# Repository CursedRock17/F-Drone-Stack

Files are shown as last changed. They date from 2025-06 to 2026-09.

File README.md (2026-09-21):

# Welcome to the F-Drone-Stack

## Introduction
This is project for the [MATRIX Lab](https://matrix.umd.edu/) at the University of Maryland's SMART
building. It utilizes dRehmFlight (by nickrehm) as a flight controller.

The intent of the project is to create a stack for replicable, autonmous
drones. These drones utilize a soft-core ARM Cortex M3 on an FPGA to
allow the software to not be restricted to any certain chip which can
be used on quadrotors of any size or scale.

Clone this repository with the version you'd like: `git clone https://github.com/CursedRock17/F-Drone-Stack.git -b humble`

## Software Setup
--------------------------------------------
### Required External Resources (Libraries)
 - Vivavdo [Download](https://www.amd.com/en/products/software/adaptive-socs-and-fpgas/vivado/vivado-buy.html)
 - ARM [Cortex M3](https://developer.arm.com/documentation/101483/0000/introduction/directory-structure) replicable architecture for Artix A7 FPGA

### CRSF Protocol Overview
 - CRSF Telemetry [PX4 Guide](https://docs.px4.io/main/en/telemetry/crsf_telemetry.html)
 - Telemtry [Messages](https://docs.px4.io/main/en/telemetry/crsf_telemetry.html#telemetry-messages)

<details>
<summary> Arduino Setup Steps </summary>

Prerequiste Installs

1. Install [Arduino](https://www.arduino.cc/en/software/) for your respective system
2. Install the [Teensyduino](https://www.pjrc.com/teensy/td_download.html) add-on for your respective system
   : *Note* Make sure you're using versino 1.57.3.
3. Install the [CRSFforArduino](https://github.com/ZZ-Cat/CRSFforArduino) library
4. Navigate to the directory in which you cloned the repo: `cd ~/user/F-Drone-Stack`
5. You have successfully installed the software stack!

</details>

<details>
<summary> Vivado Setup Steps </summary>

** Be Warned Vivado is a **FAT** install **
1. Install [Vivado](https://www.xilinx.com/support/download/index.html/content/xilinx/en/downloadNav/vivado-design-tools.html) for your OS
    1. For Linux: Download the `.bin` file, open up a terminal, `cd ~/Downloads`
    2. Make the file installable: `chmod +x <installer_name>.bin`
    3. Run install: `sudo <installer_name>.bin`
2. Go through the setup manager, you only need the free version for this project
    1. In Detail: Sign-in with your AMD account
    2. Install Vivado ML Standard
    3. In Devices, add "7-Series > Artix-7 FPGAs"
    4. Agree to all the licenses, scrolling to the bottom
    5. Install in the "/tools/Xilinx" directory, or wherever's best for you
    6. Cry as you watch your RAM wither away
        1. If you're on Linux, install the cable drivers, so we can program it: `cd /tools/Xilinx/data/xicom/cable_drivers/lin64/install_script/install_drivers`
        2. Make sure you're added, sudo adduser $USER dialout
    7. Source the install: "source /tools/Xilinx/<version>/settings64.sh"
    8. Run the program, (Linux): `vivado` (Windows): double click app
3. Install the [ARM Cortex IP](https://developer.arm.com/documentation/101483/0000/?lang=en)
    1. See if you're respective university/company already has it (UMD does!), if not apply for the [DesignStart program](https://www.arm.com/resources/program-reg/flexible-access-designstart-tier)
    2. Once you gain access go to [ARM Developer's Product Hub](https://developer.arm.com/downloads/)
    3. Go to [DesignStart Physical IP](https://developer.arm.com/downloads/search?programme=DesignStart&term=Cortex-M3+Processor&entitled=false) and grab the `Cortex M3`
4. Boot up Vivado, we can do so by sourcing the shell script:

</details>

### Running the Software
1. Open the Arduino IDE
2. We now need to open the correct version of the software to make adjustments: In the top left corner of the IDE go to “File > Open > ~/user/F-Drone-Stack/dRehmFlight/Versions/dRehmFlight_Teensy_BETA_1.3”
3. We now need to select the correct board, which in our case is the Teensy 4.1 (but 4.0 works just fine). Go to “Tools > Board > Teensy > Teensy 4.1”. Make sure CPU speed is “600 mHz” and USB type is “Serial”
4. At this point in time acquire a data transfer USB and plug it into the Teensy. We can hit “Sketch > Upload” and the board should flash the Arduino file
    1. Note an error I came across was not having the rules for the Teensy board already installed. So if you come across this error do the following:
    2. Open up a terminal window and go to the rules directory, on Linux: “cd /etc/udev/rules.d” or make the directory if it doesn’t exist “mkdir -p /etc/udev/rules.d”
    3. We need to add the Teensy Rules File, now “touch 00-teensy.rules”
    4. In the text editor of your choice, copy the entire file linked above and paste it into the file. Reflash dRehmFlight and the upload should complete
5. Enjoy!

### Flight Computer Setup Steps (Intelligence Stack)

Provides to sort of intelligence like waypoint provision, pose estimation,
and path planning access.

[In Flight Computer Section](./FlightComputer).

### Hardware Setup

[In Hardware Section](./Hardware), steps to find needed parts, assemble,
and troubleshoot the mechanical and electrical parts to a sample drone

You can also find any CAD Files and eCAD files pertaining to the drone

### Handset Setup 

While this code will work autonomously, it's a good idea as always to 
allow manual control via a human pilot, for the testing I used to the 
[Radiomaster Zorro](https://radiomasterrc.com/collections/zorro-radio-control-series/products/zorro-radio-controller).
We will flashing everything through UART and over Wifi.

1) Download the [ExpressLRS Configurator](https://github.com/ExpressLRS/ExpressLRS-Configurator/releases/)
it will make it easier to bind the Handset (Tx) to the ELRS Receiver (Rx)
2) You can plug your Teensy into a computer to get 5V passing through the receiver 
Once it is on, open that Configurator application. There will some options:
  - Releases : Whatever version you installed 
  - Device Category : BETAFPV 2.4 GHz 
  - Device : BETAFPV 2400 RX Lite 
  - Flashing Method : UART
Now, hit `Build and Flash`, it might take a couple minutes.
3) We can now flash the receiver over wifi, download the [ELRS Firmware](https://support.betafpv.com/hc/en-us/articles/24408930358169-Firmware-for-ELRS-Lite-Receiver-2-4GHz)
before you actually flash, since you'll lose access to the internet. 
After waiting about 30 secs there should be a new wifi network:
`ExpressLRS RX` with the password "expresslrs". Join it! 
4) It will automatically put you in the browser so that you can acccss 
the `Firmware Update` section, *Select* the firmware you just downloaded.
Now I had some trouble here where it would tell me there's a mismatch and kick me
out, this happened a couple of times, just repeat it 3-4 times and it will download for you.
5) We can now pair the handset, in the Zorro `Hardware` section (Page 6 in SYS) 
there's a subgroup : `Bind Configuration`, use the right scroll wheel, then press in
6) We will now do the same wifi style setup but with the TX instead.
7) Congrats the two items should be paired!

After you've paired the two together we should tune our controller for the drone.

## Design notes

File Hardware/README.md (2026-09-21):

# Hardware Section and Setup

Welcome to the mechanical and electrical parts section of the project,
here you can find the entire process of building a custom drone.

### Parts List

#### Electrical Components

| Item | Part | Datasheet | Link |
|---|---:| ---:| ---:|
| MCU/FC | Teensy 4.0 | [Datasheet](https://www.pjrc.com/store/teensy40.html) | [Link](https://www.electromaker.io/shop/product/teensy-40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)
| IMU | HiLetgo GY-521 | [Datasheet](https://mm.digikey.com/Volume0/opasdata/d220001/medias/docus/2204/SEN0142_Web.pdf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) | [Link](https://www.amazon.com/HiLetgo-MPU-6050-Accelerometer-Gyroscope-Converter/dp/B078SS8NQV)
| Radio Rx | ELRS Lite RX 2.4 GHz | [Datasheet](https://support.betafpv.com/hc/en-us/articles/4402596816409-Manual-for-Nano-Receiver) | [Link](https://betafpv.com/products/elrs-lite-receiver?variant=39582961664134)
| ESC (4in1) | Mamba F30 Mini | [Datasheet](https://cdn.shopifycdn.net/s/files/1/0027/2708/4144/files/MK4_F405_MINI_ICM42688P.jpg?v=1658891020) | [Link](https://speedyfpv.com/products/diatone-mamba-f30mini-2-5s-30a-brushless-4-in-1-esc-blheli_s-dshot600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)
| BEC (5V) | MP1584EN Mini | [Datasheet](https://www.makerfabs.com/desfile/files/MP1584.pdf) | [Link](https://www.amazon.com/MP1584EN-DC-DC-Converter-Adjustable-Module/dp/B01MQGMOKI)
| Battery (2S) | GNB Li-ion 2S | None | [Link](https://www.gaoneng.shop/products/gaoneng-gnb-2s-7.4v-3000mah-10c-xt60-li-ion-battery-made-with-sony-18650-vtc6)
| Motors (x4) | HGLRC 11000KV Brushless | [Datasheet](https://www.hglrc.com/products/specter-1202-5-11000kv-brushless-motor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) | [Link](https://www.hglrc.com/products/specter-1202-5-11000kv-brushless-motor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)
| Optical Flow | Matek 3901-L0X | [Datasheet](https://www.mateksys.com/?portfolio=3901-l0x#tab-id-2) | [Link](https://www.getfpv.com/mateksys-optical-flow-lidar-sensor-3901-l0x.html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)
| Wires | 28awg Wires + Connectors| [Datasheet](https://www.molex.com/en-us/products/part-detail/151340402?display=pdf) | [Link](https://www.amazon.com/Keszoox-Pre-Crimped-Compatible-Controller-Connectors/dp/B09F3TQS9V?th=1)
| Capacitor | 25V 330uF | None | [Link](https://www.digikey.com/en/products/detail/rubycon/25YXF330MEFCT810X12.5/9553865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)

#### Mechanical Parts

| Item | Part | Datasheet | Link |
|---|---:| ---:| ---:|
| Drone Frame | Carbon Fiber Micro UAS  | None | None
| Screws(x7) | M2 12mm Metal Screw | None | None
| Nuts(x7) | M2 Metal Nut | None | None
| Screws(x2) | M3 12mm Nylon Screw | None | None
| Nuts(x2) | M3 Nylon Nut | None | None
| Custom PCB | Copper Board | The PCB in the Hardware Section | [Hardware](TeensyDrone) 
| Battery Mount | Battery Holder | None | None
| Op Flow Mount | Op Flow Holder | None | None
| Legs(x4) | TPU printed Legs | Legs in the TeensyCAD section | [TeensyCAD](TeensyCAD)
| JST SH | 8-Pin Vertical Shrouded | [Datasheet](https://www.jst-mfg.com/product/pdf/eng/eSH.pdf) | [Link](https://www.digikey.com/en/products/detail/jst-sales-america-inc/BM08B-SRSS-TB/926700)
| MX PicoBlade (x2)| 4-Pin Vertical Picoblade| [Datasheet](https://www.molex.com/en-us/products/part-detail/533980471?display=pdf) | [Link](https://www.digikey.com/en/products/detail/molex/0533980471/699068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)
| MX PicoBlade (x4)| 3-Pin Male Connector | [Datasheet](https://www.molex.com/en-us/products/part-detail/2181100301) | [Link](www.digikey.com/en/products/detail/molex/2181100301/14309272?utm_source=oemsecrets&utm_medium=aggregator&utm_campaign=buynow)
| Gemfan 3025  (x4)| 2 Blade Propeller | [Datasheet](https://grabcad.com/library/gemfan-t-3025-1) | [Link](https://newbeedrone.com/products/gemfan-3025-pc-2-blade-propeller)

### Drone Characteristics
- Drone Weight: 97g
- 2S Li-Ion Battery Weight: 104g 
- Battery Holder Weight: 5g 
- *Total Weight*: 206g
- CG:
- Motor Thrust vs PWM Signal Curve:

### Assembly

1) Grab your drone Frame, electrical components, and turn on your soldering iron
2) Before you do anything, ensure your PCB's PWR/GND doesn't have any shorts
by testing with a multimeter, there should be 1 big GND plane
3) Use helping hands to hold the PCB still, start by soldering pinouts to tracks
    1) Start with the BEC, ensure it's in the correct orientation, arrow points left
    and solder pins 3 & 7, using the PCB editor as a guide. I placed 2 pin
    headers in each section, soldered those into the board, then sniped them flush
    2) Next we solder the Teensy 4.0 going in the clockwise direction, starting
    with Vin (the top right pin), the USB port should face the BEC, skip 4pins,
    then solder pins 21, 20, (skip 2), 17, 16, (skip 6), 3.3V, (skip 4), 9,
    8, 7, 6, (skip 4), 1, 0. You may want to solder header pins in the vertical
    pinouts of the Teensy itself, then solder matching sockets (14 pin) into
    the board itself, for easy removal of the Teensy.
    3) Solder all 4 JST headers, the 8-pin on the left, two 4-pins on the right
    and another 4-pin on the lower on the right
4) Mount the PCB to the drone frame itself, using three M2 (2") screws, they
   should lie underneath the ESC, so taking it off must be done in reverse
5) The next step is soldering 28-awg wire(Or whatever you have) with
   connectors to the components
   There are 4 components which are wired in this way:
     - ESC Motors (3 connectors each, 4 connectors) Goes RBY for colors,
     string and solder those wires to the edge power pads, then we can
     run the other end of the connector into the corresponding motor
     connectors, so they should click into each other (MX Picoblade)
     male -> female and female -> male
     - ESC (8 pin connector, using 6, top left)
     - IMU (4 pin connector, top right)
     - Optical Flow (4 pin connector, middle right)
     - ELRS (4 pin connector, bottom right)
6) *Optional* : Put a layer of Kapton tape on the bottom of the PCB
7) After we've solder all the components onto the board, we can mount things
   Things have to mounted in a weird order so that we save space
    1) Run the 3 mounting screws for the PCB, through the PCB, but not onto the
    frame
    2) Mount the ESC to the PCB using 4 M2 (2") screws with the custom spacers
    on the opposite side of the ESC, finishing with a M2 nut on the other side
    of the board
    3) The other component being mounted to the PCB is the IMU, with two
    3" screws 12mm Nylon screws. Run the screws through the IMU into rubber
    spacers (gummies) which are finished up by some tight fitting nuts on the
    other side of the PCB
    4) Flip the PCB + Drone over, slotting the mounting screws through and as
    always, finish on the otherside with M2 nuts for each of the 3 screws
8) We must now screw in the battery pack, to the bottom with the holder
9) **Before** plugging in your external connectors or the Teensy, you need to
test the BEC, since it's controlled with a potentiometer. **Ensure no component
can be fried by the 7.4V you'll get from the battery**. Do this in a controlled
environment and set up ahead of time, plug in your battery, take a multimeter
and the easy spot to test will be the back of the board where lies the
Teensy's 5V and GND pins, so being careful as to not short the two, put the
meter on each respective side. You should get about 4.95 - 5.15V, if not,
disassemble. Alternatively you could put temporary header pins into the soldered
socket and test that way. If need be, tune that potentiometer
10) After ensuring you won't fry your connectors, plug in the components.
11) You should use Waxed Nylon String or similar, with a clove hitch knot
followed by a square knot, to tie excess table bundles down to the frame
12) Place your props (not too far down) onto your motors, ensure you have
your props in the correct direction for props out. *Tip* : think about how the
air would flow if it made contact with the prop
13) The drone is now assembled!

### Steps Before Flying
There are some steps we should take, after assembling the drone,
before it gets in the air:
1) Ensure no loose connections between motors and onboard connectors, also
ensure there's no other power source, before plugging in the battery
2) Ensure the drone will not be armed before flight whether it's with a handset, some
teleop data, or an autonomous code
3) Grip the drone well and plug in the battery (2S)
4) Ensure the drone can pitch, roll, and yaw by slowly altering values to one side.
Make sure your throttle speed is low enough so it doesn't fly out of your hand. You may
also want to set RPY=0, then manually turn the drone to each of its' sides to see if
it would balance itself out.
5) Disconnect from any tether or hold on the drone, go a clear space with no unwanted
obstacles.
6) Run your process!

### General Board Setup Requirements
- 1.0mm Power/GND width
- 0.5mm Default Clearance
- 0.5mm Default Track Width + Connection Width
- No need for other trace sizes b/c not very intense
- Min Annular Width = 0.5mm
- Min Via Diameter = 1.0mm
- Copper to Hole/Edge Clearance: 0.5mm
- Min Through Hole: 0.25mm
- Hole -> Hole Clearance: 1.0mm

### Considerations for the future
- [ ] Change Header footprints to corresponding connectors
- [ ] FlipFlop the Servo connector so on the board it's 1 -> 1
- [ ] Since we have access to PCBWay, should probably route more concisely
- [ ] Check the spacing for our headers to ensure the physical part fits
- [ ] Check the spacing from connector to other components like ESC conn. to BEC
- [ ] Reverse order pins for IMU since not enough space
- [ ] Smaller Pitch Surface MNT connectors
- [ ] Enable Clearance for Props (maybe create design of frame and all)
- [ ] Rotate IMU so that it faces front (X points to front)
- [ ] Create a more indepdent, less noisy mount for the correctly rotated IMU (Sticky pads too fragile)
- [ ] Create larger traces for the motors since they drive a lot of current
- [ ] Make the drone colors MD-themed (Red/Black) for legs and frame and maybe props
- [ ] Create a more precise battery mount, mainly for Li-ion battery
- [ ] Make legs a bit wider as Bill said they would stick better
- [ ] Ensure access to Telemetry data from the ESC

### CAD Files
Listed in the directory are the URDF files and JSON config for F-Drone. In order to use 
F-Drone in simulation it needs to be converted to URDF, which should be saved here, but 
if  you update the CAD files, it shouldn't be hard to get those URDFs. 
Instead, we can use `onshape-to-robot`.

<details>
<summary> How to Convert from CAD to URDF (OnShape) </summary>

Prerequiste Installs
- Install onshape-to-robot through `pip install onshape-to-robot`
- Install meshlab through `sudo apt-get install meshlab` (Or whatever your system is)
- Install openscad through `sudo apt-get install openscad` (Or whatever your system is)

1. You need to generate some keys to your OnShape account - navigate to the 
[API Keys](https://cad.onshape.com/appstore/dev-portal/apiKeys) section of OnShape.
2. Click 'Create a new API key' in the top right corner, enable all of the permissions
3. **Wait** you wil provided will a access key and secret key, we need to save them.
4. Open a terminal instance and navigate to the `Hardware` section of the project.
5. Create a script to rerun: `touch onshape.bash`, paste in the following
```
# Access Our CAD files
export ONSHAPE_API=https://cad.onshape.com
export ONSHAPE_ACCESS_KEY=YOUR_ACCESS
export ONSHAPE_SECRET_KEY=YOUR_SECRET
```
You can also use a `.bashrc` or `.env` file if you prefer, then give it run permisions:
`chmod +x onshape.sh` && `source onshape.sh`
6. Run the script, `./onshape.sh` to get those keys 
7. Now anytime you update the CAD file given the document in the `url` section of the 
config.json, you can run `onshape-to-robot ./path-to-config-file` replacing it with your path

</details>

### Key Details to resolve Issues

<details>
<summary> Calibration Sequence Won't Fire </summary>
When in calibration mode, if you don't here the special jingle after arming, one of two things happened.
Either there's not enough "IDLE" time before the calibration due to delays. Or, the range is not
correctly setup for the controller which causes the OneShot125 Protocol to miss the trim
</details>

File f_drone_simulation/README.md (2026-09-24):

# f_drone_simulation
This folder is based on the [ros_gz_template_project](https://github.com/gazebosim/ros_gz_project_template) which is the correct way to define ROS 2 / Gazebo projects. 
While we are technically ROS agnostic, we should still follow Gazebo guidelines as they apply well.
In accordance to the project [guidelines](https://gazebosim.org/docs/latest/ros_gz_project_template_guide/) this project pairs ROS and Gazebo variants, so for `jazzy` we're using `harmonic`.

## Getting Started
This part of the project will expand in the future. The easiest way to run project is to start by launching the various examples
Enter the project, source the workspace, build, and launch as such:

```shell
export ROS_VERSION=jazzy
export LAUNCH_NAME=whatever_launch

source /opt/ros/${ROS_VERSION}/setup.bash
colcon build --base-paths f_drone_simulation && source install/setup.bash
ros2 launch f_drone_bringup ${LAUNCH_NAME}.launch.py
```

You can replace `whatever_launch` with whatever name of the launch file you want to run from the following.

| LAUNCH_NAME | Description | launch arguments |
|---|---|---|
| [crazy_launch](f_drone_bringup/launch/crazy_launch.launch.py) | This is meant to be a dry-test run with a standard Crazyflie drone which has been proven to work with the teleop GUI | None |
| [mini_shell_launch](f_drone_bringup/launch/mini_shell_launch.launch.py) | OnShape-derived drone with Gazebo teleop, live URDF/TF, and Foxglove | `gazebo_gui`, `foxglove_gui`, `foxglove_port` |
| [mini_shell_hil](f_drone_bringup/launch/mini_shell_hil.launch.py) | Mini-shell IMU/range sensors and motor models connected to the Teensy through DroneSerial | `serial_port`, `gazebo_gui` |
| [simple_drone](f_drone_bringup/launch/simple_drone.launch.py) | Newer drone export with live URDF, fixed/moving TF, and Foxglove | `gazebo_gui`, `foxglove_gui`, `foxglove_port` |

Run these commands from the repository root; see the
[Gazebo and Foxglove example](docs/basic_gazebo_foxglove_example.md)
for the saved layout, first-time setup, and verification steps.
For the newer `models/drone` export, use the
[drone Foxglove guide](docs/drone_foxglove.md).
For Teensy integration, use the [mini-shell HIL guide](docs/mini_shell_hil.md),
including the firmware checks required before running powered actuators.

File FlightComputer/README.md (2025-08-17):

# Flight Computer

## Setting up the Software

### PreRequisites
  - ROS 2 Humble [Installed](https://docs.ros.org/en/humble/Installation.html)
  - Python's Pip has been [Installed](https://pypi.org/project/pip/)
  - The virtual environment Pipenv has been [Installed](https://pipenv.pypa.io/en/latest/)
  - MAVROS [Installed](https://github.com/mavlink/mavros/blob/ros2/mavros/README.md#installation)

### Installing micro-ROS
We Need to install micro-ROS to allow our Teensy to communicate with its
surroundings whether that be ground control or other Teensies

*Note* I'm doing this in Ubuntu 22.04, where ROS 2 presents us as a Tier 1 OS
if you choose another platform the process should remain the same, but you
may find it to be a bit more difficult.
```
source /opt/ros/humble/setup.bash

# Create A Working Directory from which we have a stable micro-ROS setup
mkdir -p microros_ws/src && cd microros_ws/src
git clone https://github.com/micro-ROS/micro_ros_setup.git src/micro_ros_setup -b humble

# Ensure Our dependencies are in line with the version
sudo apt update && rosdep update

rosdep install --from-paths src --ignore-src -y

# Use the colcon buildchain tool to set up our resources
colcon build && source install/local_setup.bash
```
This install provides us with a setup agent for micro-ROS which will walk
us through some install steps
```
ros2 run micro_ros_setup create_agent_ws.sh
# Then
source install/local_setup.bash
# Then
ros2 run micro_ros_setup build_agent.sh
# Then
source install/local_setup.bash
```
At this point in time plug in your choice of Teensy into the board and ensure
it has the ability to flash, *Note* ensure the USB Micro-B Cable can do data transfer
```
ros2 run micro_ros_agent micro_ros_agent serial --dev /dev/ttyACM0
```

### Issues/Resolutions

<details>
<summary> Teensy Hardware Issues </summary>

You may stumble into ROS definitions not being recognized under the guise of 
"no precompiled library support". First make sure you're using Teensy 1.57.3, which
you can alter in the board manager by searching "teensy". We then need to upload 
a new hardware patch, [found in](https://github.com/micro-ROS/micro_ros_arduino/blob/kilted/extras/patching_boards/platform_teensy.txt) the microROS github.

Navigate to the original install location of the Teensy firmware :
`cd ~/.arduino15/packages/teensy/hardware/avr/1.57.3`, then
replace the `platform.txt` file with the contents of the micro_ros patch
`curl https://raw.githubusercontent.com/micro-ROS/micro_ros_arduino/refs/heads/kilted/extras/patching_boards/platform_teensy.txt > platform.txt` should do the trick.

</details>

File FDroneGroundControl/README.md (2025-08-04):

# FDroneGroundControl

This package will serve as a form of source control we can use to manage any singular drone up to 
a fleet of drones. It's a great way to monitor active data with the project.

### Planned Features:
  - OpenRMF Fleet Management
  - Mavlink Ground Control
  - Foxglove Visualization

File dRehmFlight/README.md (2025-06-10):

## Overview
dRehmFlight is the flight controller for hobbyists, hackers, and non-coders interested in stabilizing their wacky and unique flying creations. The code and supporting documentation is built to bring someone up to speed on VTOL flight stabilization concepts as quickly and painlessly as possible. The code is written and presented in a way that is intuitive, easy to follow, and most importantly: all in one place. No more digging through countless folders and confusing classes just to add an 'if' statement for your custom drone application. This flight controller uses an Arduino-compatible microcontroller, so there is no confusing flashing or compiling process necessary. If you can use Arduino, you can start expanding the capabilites of this flight controller to your liking.

dRehmFlight has been used as a teaching tool for aircraft stabilization and flight control principles in universities and tech companies around the world. It is not meant to out-perform other flight controller packages on the market, or be used in a commercial sense. It is best suited for rapid prototyping or allowing a radio control hobbyist to get their feet wet in flight control code for their VTOL project. Much more information is included in the dRehmFlight VTOL Documentation .pdf.

This code is entirely free to use and will stay that way forever. If you found this helpful for your project, donations are appreciated: [Paypal Donation](https://www.paypal.me/NicholasRehm)

### Hardware Requirements
This flight controller is based off of the Teensy 4.0 microcontroller and MPU6050 6DOF IMU. The following components (available on Amazon) are required to complete the flight controller assembly:

**Teensy 4.1**: https://amzn.to/3oFG3QN

**GY-521 MPU6050 IMU**: https://amzn.to/3edF1Vn

These (and all Amazon links contained within the supporting documentation) are Amazon Affiliate links; by purchasing from these, I receive a small portion of the revenue at no cost to you. I appreciate any and all support! [Buy all of the parts here.](https://www.amazon.com/shop/nicholasrehm/list/1NDPB7E0VMZOP?ref_=aip_sf_list_spv_ons_mixed_d)

### Software Requirments
Code is uploaded to the board using the Arduino IDE; download the latest version here: https://www.arduino.cc/en/main/software
To connect to the Teensy, you must also download and install the Teensyduino arduino add-on; download and instructions available here: https://www.pjrc.com/teensy/td_download.html

## Disclaimer
This code is a shared, open source flight controller for small micro aerial vehicles and is intended to be modified to suit your needs. It is NOT intended to be used on manned vehicles. I do not claim any responsibility for any damage or injury that may be inflicted as a result of the use of this code. Use and modify at your own risk. More specifically put:

THIS SOFTWARE IS PROVIDED BY THE CONTRIBUTORS "AS IS" AND ANY EXPRESS OR IMPLIED WARRANTIES, INCLUDING, BUT NOT LIMITED TO, THE IMPLIED WARRANTIES OF MERCHANTABILITY AND FITNESS FOR A PARTICULAR PURPOSE ARE DISCLAIMED. IN NO EVENT SHALL THE CONTRIBUTORS BE LIABLE FOR ANY DIRECT, INDIRECT, INCIDENTAL, SPECIAL, EXEMPLARY, OR CONSEQUENTIAL DAMAGES (INCLUDING, BUT NOT LIMITED TO, PROCUREMENT OF SUBSTITUTE GOODS OR SERVICES; LOSS OF USE, DATA, OR PROFITS; OR BUSINESS INTERRUPTION) HOWEVER CAUSED AND ON ANY THEORY OF LIABILITY, WHETHER IN CONTRACT, STRICT LIABILITY, OR TORT (INCLUDING NEGLIGENCE OR OTHERWISE) ARISING IN ANY WAY OUT OF THE USE OF THIS SOFTWARE, EVEN IF ADVISED OF THE POSSIBILITY OF SUCH DAMAGE.

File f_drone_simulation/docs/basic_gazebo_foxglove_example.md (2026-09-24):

# Basic drone simulation: Gazebo and Foxglove

## Purpose

Start with one OnShape-derived drone in an otherwise empty world with a
ground plane and light. Fly it using Gazebo's GUI teleop controls and watch
the same motion in Foxglove. This is the first end-to-end example before
adding sensors, autonomy, or hardware in the loop (HIL).

The SDF supplies Gazebo's geometry, collisions, mass, inertia, joints, and
simulation plugins. The matching URDF supplies Foxglove's visual model and
link structure. Both must represent the same CAD assembly and use consistent
units, link names, and coordinate frames.

## Launch behavior

The mini-shell launch now:

1. Opens Gazebo with the drone included in the basic world.
2. Starts the flight controller and the Gazebo GUI teleop panel.
3. Starts the ROS–Gazebo bridge for commands, simulation time, and state.
4. Publishes the URDF and the transforms needed to position its links.
5. Starts the Foxglove bridge and opens the installed Foxglove desktop app
   with a connection to `ws://localhost:8765`.

Import the saved Foxglove layout once using the instructions below.

Gazebo runs the physics; Foxglove displays the resulting state using the
URDF. Loading an SDF in Gazebo does not automatically publish a URDF or
make the drone move in Foxglove.

```text
Gazebo GUI teleop → ROS–Gazebo bridge → teleop mapping
    → ROS–Gazebo bridge → flight controller → motors → simulated motion

Gazebo pose, joint state, and clock → ROS–Gazebo bridge
    → ROS transforms + URDF → Foxglove bridge → Foxglove 3D panel
```

The visualization needs a world-to-body transform from the simulated pose,
plus link transforms from `robot_state_publisher`; moving joints need joint
states. ROS nodes using simulation time must receive `/clock`.

## What works today

As checked on September 21, 2026, the project builds with ROS 2 Jazzy and
Gazebo Harmonic, and the mini-shell launch accepts commands through the
ROS–Gazebo bridge and produces upward motion. The integration test checks
that the URDF, clock, joint states, and all five link transforms are
available and that the body transform follows Gazebo odometry during flight.

A separate WebSocket check received the live URDF, all five TF edges, and
all nine referenced mesh files through the Foxglove bridge. Desktop rendering
has not yet been visually confirmed: the isolated desktop test profile
stopped at Foxglove's sign-in screen. Use your signed-in session to import
the layout and confirm that the model stays assembled during teleop.

From the repository root, build and start the example:

```bash
source /opt/ros/jazzy/setup.bash
colcon build --base-paths f_drone_simulation
source install/setup.bash
ros2 launch f_drone_bringup mini_shell_launch.launch.py
```

Relevant files:

- [Launch file](../f_drone_bringup/launch/mini_shell_launch.launch.py)
- [Basic world](../f_drone_gazebo/worlds/mini_shell.sdf)
- [Simulation model](../f_drone_description/models/mini_shell/model_teleop.sdf)
- [Visualization model](../f_drone_description/models/mini_shell/model.urdf)
- [Bridge configuration](../f_drone_bringup/config/mini_shell_bridge.yaml)

## Foxglove setup and TF

In Foxglove's layout menu, import
[mini_shell_gazebo_viewer.json](../f_drone_bringup/config/mini_shell_gazebo_viewer.json).
This is the Foxglove layout; `mini_shell_gui.config` configures Gazebo's GUI
and cannot be imported as a Foxglove layout.

The layout reads `/robot_description` and uses TF to place the model's
links, with `base_link` as the camera-follow frame. Meshes are fetched from
the sourced description package through the bridge, so the layout does not
need a machine-specific URDF path. A file-based URDF layer is also valid,
but selecting transform control still requires the matching TF stream.

```text
world                         Gazebo's simulated pose, bridged to /tf
└── base_link
    ├── prop                  robot_state_publisher, from /joint_states
    ├── prop_2
    ├── prop_3
    └── prop_4
```

| ROS topic | Purpose |
| --- | --- |
| `/robot_description` | URDF published by `robot_state_publisher`, retained for late connections |
| `/joint_states` | Actual Gazebo rotor angles and velocities |
| `/tf` | World-to-body pose and body-to-propeller transforms |
| `/clock` | Gazebo simulation time |
| `/mini_shell/odometry` | Simulated body pose and velocity for comparison and plotting |

The URDF has four movable joints and no fixed joints, so no fixed-link
transforms are expected on `/tf_static`. Each transform has one owner:
Gazebo publishes `world → base_link`, and `robot_state_publisher` publishes
the four propeller transforms. The base link and SDF model origin coincide.

For an already-open Foxglove client, append `foxglove_gui:=false` to the
launch command and connect to `ws://localhost:8765` manually. The bridge
still runs. Use `gazebo_gui:=false` for server-only Gazebo, or
`foxglove_port:=8877` if another bridge already uses port 8765. The bridge
binds to localhost for this same-machine example.

Useful checks, in another terminal with ROS and the workspace sourced:

```bash
ros2 topic echo /joint_states --once
ros2 run tf2_ros tf2_echo world base_link
ros2 run tf2_ros tf2_echo base_link prop
```

Stop each continuous TF check with Ctrl+C before running the next command.
The integration regression runs with `colcon test --packages-select
f_drone_bringup`, followed by `colcon test-result --verbose`; on this machine,
prefix the test command with `CTEST_COMMAND=/usr/bin/ctest` to bypass the
obsolete local CTest wrapper.

See [Robot State Publisher](https://github.com/ros/robot_state_publisher/tree/jazzy)
and the [Foxglove 3D documentation](https://docs.foxglove.dev/docs/visualization/panels/3d)
for the underlying URDF and transform behavior. The existing KDL warning
about root-link inertia does not prevent visualization; Gazebo continues
to use the SDF inertial properties for physics.

## Controls

The existing mapping uses W/S for forward/backward, Q/E for up/down, and
A/D for left/right. These request velocity; the flight controller produces
the attitude changes and motor thrust needed to move the drone.

The current mapping converts the teleop panel's yaw input into lateral
motion, so **independent yaw control is still needed** to cover translation
and heading together. This example does not provide direct manual throttle,
roll, or pitch commands to dRehmFlight; that belongs to the later HIL stage.

## Recorded demonstration

On September 21, 2026, the operator reported successful manual checks of
roll, pitch, yaw, and throttle response in Gazebo and supplied the following
screenshot and recording. The exact yaw input used for that check still
needs documenting because the launch mapping above repurposes yaw as
lateral motion.

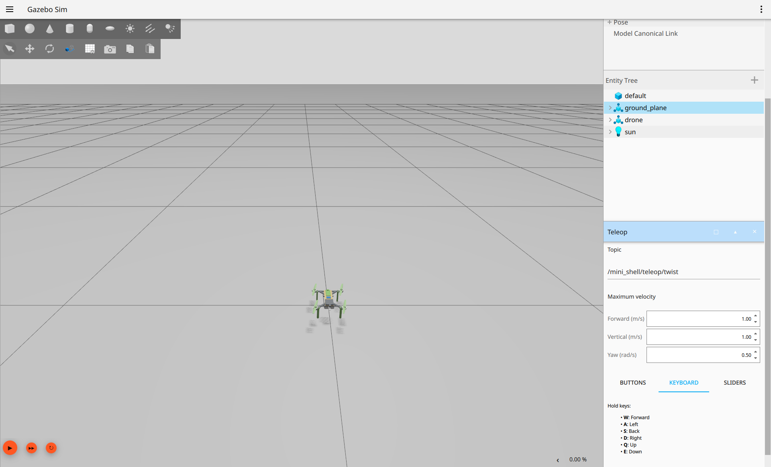
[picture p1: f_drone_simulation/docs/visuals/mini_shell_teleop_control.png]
Mini-shell drone and Gazebo teleop controls


The animation shows the full recording at 12 frames per second, scaled to
960 pixels wide for viewing in this document.

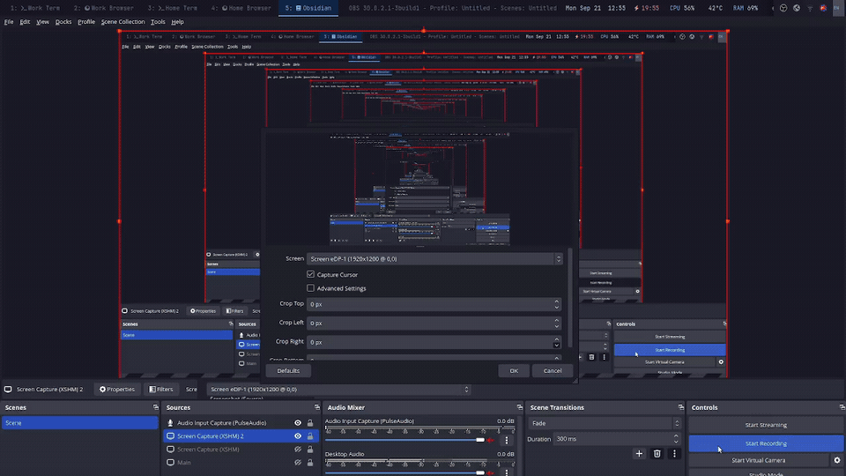
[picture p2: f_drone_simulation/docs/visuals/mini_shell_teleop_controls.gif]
Animated demonstration of mini-shell teleop in Gazebo


[Download the original video with audio (MKV)](visuals/mini_shell_teleop_controls.mkv).

This recording predates the Foxglove integration and documents Gazebo only;
world-reset behavior and a matching Foxglove demonstration remain separate
checks.

## Completion checks

- One launch opens both applications and starts the required bridges and
  publishers, without manual topic wiring.
- The drone's meshes and link placement render correctly in both viewers.
- The drone rests on the ground without falling through it or moving
  unexpectedly; mass, inertia, and collisions are checked against the CAD
  assembly and available physical measurements.
- Small commands produce the expected vertical, forward/backward, lateral,
  and yaw response; stopping commands stops the requested motion.
- Foxglove follows Gazebo's position, orientation, and relevant joint motion
  with consistent simulation timestamps.
- A full world reset restores exactly one drone to its starting state,
  clears prior commands, and leaves teleop and visualization usable.
- If respawning a deleted drone is required, deletion followed by reset is
  tested explicitly rather than assuming pose reset recreates the entity.

Record each issue with the model/version, launch command, input, expected
behavior, observed behavior, and relevant logs or screenshots. A successful
import or short climb alone does not establish physical fidelity or a
validated flight envelope.

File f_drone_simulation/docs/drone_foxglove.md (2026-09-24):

# Visualize the newer drone in Foxglove

This example uses `models/drone/urdf/drone.urdf` and `drone.sdf`, rather
than the mini-shell export. Run one example at a time because both use
`/robot_description`, `/joint_states`, `/tf`, and the default Foxglove port.

From the repository root:

```bash
source /opt/ros/jazzy/setup.bash
colcon build --base-paths f_drone_simulation
source install/setup.bash
ros2 launch f_drone_bringup simple_drone.launch.py
```

The launch opens Gazebo and the installed Foxglove desktop app and starts
both bridges and `robot_state_publisher`. In your signed-in Foxglove session,
connect to `ws://localhost:8765` and import
[simple_drone_foxglove.json](../f_drone_bringup/config/simple_drone_foxglove.json)
from the layout menu. Use `foxglove_gui:=false` if Foxglove is already open.

## How the model stays assembled

The layout reads the live `/robot_description` topic and positions the
links using TF. The URDF references meshes installed in the
`f_drone_description` package; a model folder named `drone` is not itself
a ROS package. Foxglove retrieves these meshes through its bridge.

Gazebo publishes `world → root` on `/drone/tf`, which the ROS–Gazebo bridge
forwards to `/tf`. The URDF's fixed joints, including `root → base_link`,
are published by `robot_state_publisher` on `/tf_static`; its four movable
propeller joints use the actual Gazebo `/drone/joint_states` data bridged
to `/joint_states`. This gives all 23 URDF links a path to `world`.

The ROS `/clock` topic comes from `/world/simple_drone_world/clock`.
The bridge and state publisher use simulation time, so this world name
must match the SDF world exactly.

## Check the result

With the workspace sourced in another terminal:

```bash
ros2 topic echo /clock --once
ros2 topic echo /joint_states --once
ros2 run tf2_ros tf2_echo world prop__1_
```

Confirm that Foxglove displays the battery, electronics, legs, motors, and
propellers assembled together and follows Gazebo's pose. The saved layout
follows `base_link`; choose `world` as the display frame when inspecting
motion relative to the ground. Stop continuous TF inspection with Ctrl+C.

The regression in `f_drone_bringup` checks mesh resolution, simulation time,
all link transforms, joint-origin placement, and agreement between body TF
and odometry for this model. It also retains the mini-shell climb check;
passing the newer drone's visualization check does not certify its flight
controller or physical parameters.

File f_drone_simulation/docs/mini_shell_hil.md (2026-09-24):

# Mini-shell hardware in the loop

This variant uses the existing `DroneSerial` protocol to send Gazebo IMU and
range measurements to the Teensy and apply its four motor outputs in Gazebo.
The Teensy runs the estimator and controller; the Gazebo teleop velocity
controller is absent from this model.

## Run

Build and source from the repository root, then launch with the Teensy's port:

```bash
source /opt/ros/jazzy/setup.bash
colcon build --base-paths f_drone_simulation --executor sequential
source install/setup.bash
ros2 launch f_drone_bringup mini_shell_hil.launch.py serial_port:=/dev/ttyACM0
```

Use `gazebo_gui:=false` for the server with headless sensor rendering.
The launch creates a temporary world with the selected serial port and removes
it on shutdown; it does not edit the installed model.
No ROS or Foxglove bridge is needed for this Gazebo Transport ↔ serial loop.
Radio commands and arming remain firmware responsibilities; the Gazebo keyboard
teleop controller does not control this variant.

**Before connecting powered actuators:** the checked-in firmware's
`simulatedEnvironment = true` selects simulated inputs, but `loop()` still calls
`commandMotors()` and `setup()` calls `armMotors()`; keep the ESCs disconnected
for this bench session until SIM mode explicitly isolates physical motor outputs.
This model change does not modify or flash firmware.

## Model and sensors

[`model_hil.sdf`](../f_drone_description/models/mini_shell/model_hil.sdf)
retains the geometry, collisions, mass, inertia and center of mass from the CAD
`model.sdf`, without the artificial center-of-mass correction used by
`model_teleop.sdf` for Gazebo's velocity controller.
The four motor models retain the teleop variant's parameters: 5760 rad/s maximum,
`motorConstant = 6.0e-08`, and visual rotor slowdown of 20.
These carried-over parameters are a starting point, not new hardware calibration.

| Component | Configuration |
| --- | --- |
| IMU | `base_link`, CAD IMU position, 1000 Hz, `/mini_shell/imu` |
| IMU orientation | Yaw −π/2, inherited from the old HIL model |
| Rangefinder | `base_link`, `(0, 0.055, -0.0045)` m, downward single ray, 100 Hz, 0.01–2 m, `/mini_shell/range` |
| Sensor systems | World-level `Imu` and `Sensors` with Ogre2 |
| Serial plugin | `DroneSerial`, both link names `base_link` |
| Motor commands | `/mini_shell/gazebo/command/motor_speed` |
| State outputs | `/mini_shell/odometry`, `/mini_shell/tf`, `/mini_shell/joint_states` |

The body nose points along CAD +Y; rotor indices match the firmware mixer:

| Telemetry index | Joint | Position | Rotation |
| --- | --- | --- | --- |
| 0 | `motor_prop_1` | Front left | CCW |
| 1 | `motor_prop_2` | Rear left | CW |
| 2 | `motor_prop_3` | Front right | CW |
| 3 | `motor_prop_4` | Rear right | CCW |

The rangefinder mounting position is inherited from the old simulation and needs
confirmation against the actual sensor mount; it measures distance from the
sensor, not world altitude of `base_link`.
The IMU mounting convention also needs a controlled roll/pitch/yaw sign check
against the Teensy estimator and mixer before attempting closed-loop flight.
Sensors currently have no added noise or bias, and no optical-flow source is
implemented.

## Existing wire protocol

The PDF's CRC/sequence/timestamp protocol is a proposal; this integration retains
the protocol implemented by `dRehmFlight.ino` and `DroneSerial`:

- PC → Teensy: `AA 55`, seven float32 values `(ax, ay, az, gx, gy, gz, range)`, `FE`: 31 bytes.
- Teensy → PC: seven float32 values `(timestamp, roll_PID, pitch_PID, yaw_PID, posZ, desZ, z_PID)` followed by four uint16 motor values: 36 bytes, without framing.
- Acceleration is in m/s², angular velocity in rad/s, and range in meters; firmware converts the IMU values for its estimator.
- Motor values use OneShot125: 125–250 maps linearly to 0–5760 rad/s, with clamping; disarmed 120 maps to zero.
- Host and Teensy use little-endian binary layouts; there is no CRC or sequence number.

`DroneSerial` now accepts `imu_topic`, `rangefinder_topic`, and `actuator_topic`
SDF parameters; omitting them preserves the old `/imu`, `/radar`, and
`/drone/gazebo/command/motor_speed` defaults.

## Verification and remaining work

The automated test launches the actual HIL world using a pseudo-terminal as a
virtual Teensy, receives framed sensor data, checks stationary gravity and ground
range, sends firmware-format telemetry, and checks all four published motor
speeds, including disarmed clamping.
It requires the Gazebo Harmonic Python bindings (`gz.transport13`, `gz.msgs10`)
and a working Ogre2 headless rendering environment.

```bash
source /opt/ros/jazzy/setup.bash
source install/setup.bash
python3 -m pytest -q f_drone_simulation/f_drone_bringup/test/test_mini_shell_hil.py
```

This passes without a physical Teensy and does **not** establish stable flight,
altitude hold, measured latency, or real-time performance.
Before those tests, resolve these existing implementation issues:

- The firmware sensor parser writes the footer at index 28 of a 28-byte buffer; remove that out-of-bounds write and validate complete packets before using them.
- SIM mode must suppress physical motor outputs in both startup and the control loop.
- The serial bridge uses blocking reads, assumes telemetry arrives in one complete read, and lacks a command timeout; fragmented or stopped telemetry is not handled robustly.
- World reset closes the bridge's serial port without reopening it; fully stop and relaunch this HIL launch for now, with firmware state reset separately.
- Sensor callbacks and serial packing currently share data without synchronization; invalid range samples retain the previous range.
- Firmware mass, hover feed-forward, gains and range offset need checking for mini-shell, whose CAD model totals about 0.208 kg; the checked-in firmware still declares about 1.079 kg.

Successful sensor fusion on the previous drone supports reusing the bridge, but
these checks are still necessary for control of this airframe.

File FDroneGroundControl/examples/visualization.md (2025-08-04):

# Visualization

### Prerequisites
  - Download [Foxglove](https://foxglove.dev/download)
  - Install Foxglove -> ROS 2 Bridge `sudo apt install ros-humble-foxglove-bridge` 
  - micro_ros_f_drone & dRehmFlight prepared

1) Turn on the drone and run the uROS node for "Odometry"

2) Turn on Foxglove visualization
    `ros2 launch foxglove_bridge foxglove_bridge_launch.xml`

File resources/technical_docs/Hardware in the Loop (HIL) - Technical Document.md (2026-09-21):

This document discusses the plan for implementing hardware in the loop.

We need to run the Arduino code running on the Teensy, within Gazebo, best way to do this is via plugins, which can connect to the drone sdf model by interfacing data over Serial Port between Teensy and Gazebo. Refering back to the large overview of our system:
![[Sensor Components.svg | 700x800]]
We can replace the two blocks `IMU` and `Matek-3901` with two sensors in Gazebo with their corresponding plugins (respectively): 
```
<sensor type="imu"/>
<sensor type="gpu_lidar"/>
```
The intent is to have to mimic as little as possible, we should be able to run of the regular 
Teensy code, just inserting the values from the stream into their physical counterparts. 
All we have to do is let the Teensy know the values are simulated as to not prioritize the real sensors, 
the Teensy should be on during this process. In fact, nothing other than tuning parameters should be
changed on the side of the Teensy as to transition from simulation to real as smoothly as possible.

### Things to Address:
- How do we get the Teensy to run in Gazebo, while in real life? -> Use the Serial Port
- How can we replicate dRehmFlight code in Gazebo Plugin -> No need to do so, in fact we shouldn't, bad behavior.
- How can we replicate PWM to Motor Speeds? Utilize a simulated ESC profile which uses collected data
from the motor/prop configuration within some equations.
- How are we able to run a realistic simulation at the correct 2KHz Loop Rate that dRehmFlight requires?

### Required Plugins:
- IMU         (IMU sensor)
- Teensy 4.0  (SerialData, custom plugin)
- Rangefinder (GPULidar sensor)
- Motors      (MulticopterMotorModel)

### Components and Loop
- #### Gazebo Ignition (physics & sensors)
    - Simulates drone dynamics.
    - Provides simulated **IMU** and **rangefinder** readings.
    - A **custom plugin** collects these simulated values and writes them over the serial port (e.g. `/dev/ttyACM0`).    
- #### Teensy 4.1 (real hardware, Arduino sketch)
    - Reads the sensor packets from serial instead of physical IMU/rangefinder.
    - Runs your PID / altitude controller logic.
    - Produces PWM outputs for motors (normally to ESCs).
    - Instead of toggling pins, it serializes those PWM values and sends them back over serial.
- #### Gazebo plugin (actuator side)
    - Reads motor PWM values from the Teensy.
    - Converts them to thrust & torque.
    - Applies those forces to the rotor joints in the physics engine.

[list2mermaid]

- Gazebo_Sensors
	- Teensy
		- Gazebo_Sim
			- Gazebo_Sensors

### Correctly setting up the simulated motors 

#### Getting Real Results
There are many thing that need high fidelity as we look to transition from simulation to real life,
one of which is our motors. The Plugin that Gazebo natively offers, `MulticopterMotorModel` is great,
but there are some constants which need filling out. If you should find uncertainty w/provided
datasheets for your motor/prop configuration, you can test up a weighted test stand on top of a scale.
Attach one motor and one prop to the test stand in normal configuration, but you want the air to blow
up such that you get the accurate value of thrust in grams. 

You can use this Matlab script to help visualize your acquire data:
```
%% HGLRC 1202.5 11000 KV Motor + Gemfan 3018-2 2.5" props - 7.6v
% Variables Relating to Your Setup
max_voltage = 8.4;
voltage_used = 7.6;
given_kv = 11000;

% Acquired Data
pwm_percent = [10 20 30 40 50 60 70 80 90 100];
force_output = [3.6 15.8 22.0 29.2 33.1 46.8 48.5 51.5 53.3 55.2];

% Plot the Point, the connect with a line
figure(3);
plot(pwm_percent, force_output, '-og', 'MarkerSize', 15, 'LineJoin', 'round');
grid on;

xlabel('PWM Percentage');
ylabel('Thrust Force (g)');
xlim([0, 110]);
title('PWM Percentage versus Prop Thrust Generated');
```

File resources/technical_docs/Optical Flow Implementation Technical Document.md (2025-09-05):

#### Overall Objective: Attach an optical flow sensor to our drone and fuse the sensor data in dRehmFlight.

#### Hardware Connection: 
We need to mount the Matek 3901-L0X Optical Flow Sensor to the front of the drone, with not too many loose wires, connected to the Teensy 4.0.
	Need 2 M3 screw hole embedded in a printed mount, which has some overhang to clear the drone frame and a slot so that the 4 wire pads are accessible. 4 Wires will be soldered to each of the pads and put into a connector, the male connector will mate with a female connector, which is soldered directly onto the PCB. There are already 4 pads prepared for the addition of 1 UART device. Pinouts as followed:
		- Teensy Pin 16 (TX of OpFlow)
		- Teensy Pin 17 (RX of OpFlow)
		- GND
		- 5V
	We can then click in the 2 connectors and tie it to the frame with Nylon Wax string. We should prefer some sort of stabilized house/socket to the board.

#### Software Implementation:
Utilizes 1 UART port, leaves us with 3 remaining, at 115200 Baud Rate. Uses [UART MSP V2](https://github.com/iNavFlight/inav/wiki/MSP-V2) for the communication protocol. We can write a small header file library for it for the slight performance boost and more control. That being said we get access to 65536 bits of payload data which is plenty and there have been no complaints of lossy data. Data passed as Hexadecimal, we can use the Arducopter [reference](https://github.com/ArduPilot/ardupilot/blob/master/libraries/AP_MSP/msp.cpp) to decipher the payload buffer and extract the data. Each of the 3 pieces of data are max [int32_t](https://github.com/ArduPilot/ardupilot/blob/5d9f435e48ce1ee2792ec8b8fa048b0142105fd4/libraries/AP_MSP/msp_sensors.h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).

To utilize the data given from the sensor, we will be implementing sensor fusion with the IMU. It's important to provide an optional argument in actually using the optical flow sensor in case we would like to remove it in the future, or test with other sensors. We already have attitude estimation (Roll, Pitch, Yaw) from the Madgwick Filter, but we can get pose estimation (X, Y, Z) from the Optical Flow sensor package using an Extended Kalman Filter, using the IMU as a supplement.

[list2pumlWBS]

- EKF
	- PWM3901 OpFlow Sensor
	- ST VL53L0X Rangefinder
	- MPU6050 (IMU)
		- Accelerometer
		- < Gyroscope

#### Benefits
- Allows for position hold and height adjustment on non flat surface
- Provides Velocity Estimation, thus allowing for Trajectory based waypoints
- Limited to 40mA of current
- Allows us to work in GPS denied environments and works intraprocessly
#### Drawbacks
- Limited use to indoor environments, the Matek 3901-L0X has a range of 2cm -> 200cm
- Uses 5V to power the device, may need to do some flight testing with and without
- Cannot provide navigation ability *within itself*, Cannot see surroundings

##### Useful Resources:
https://www.mateksys.com/?portfolio=3901-l0x#tab-id-3
https://github.com/iNavFlight/inav/wiki/MSP-V2
https://forum.arduino.cc/t/problem-in-converting-the-mspv2-to-get-flow-x-flow-y-and-distance-from-module-optical-flow-lidar-sensor/1281208/12
https://github.com/jagennath-hari/Project-3-UKF/tree/7dc175fe0f9440d320c4b40e9311bcc8955398c4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
https://www.mdpi.com/1424-8220/24/7/2183#FD3-sensors-24-02183
file:///home/cursedrock17/Downloads/Resumo%20Alargado.pdf

[**key**](https://github.com/ArduPilot/ardupilot/blob/5d9f435e48ce1ee2792ec8b8fa048b0142105fd4/libraries/AP_MSP/msp_sensors.h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)

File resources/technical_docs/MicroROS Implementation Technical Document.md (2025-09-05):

#### Overall Objective: Utilize MicroROS to allow our drone to communicate with external interfaces.

##### Communication Layer: 
MicroROS utilizes micro-XRCE-DDS as the middleware layer, which has a set memory profile. It starts with an XRCE Agent which acts as the server, while each connected device (the Teensy 4.0 in our case) acts as the client. That being said, it utilizes a publisher/subscription interface to communicate over WiFi (IoT) or Serial Port or even a customizable interface. It can handle messages up to 512 bytes in size.

##### External Communication: 
Our first form of communication should take place between 1 drone and 1 ground station, we can create regular `rclcpp` or `rclpy` nodes on that ground station and communicate via Serial port. We can ensure that the communication of messages (any type) flows between the serial port and the Teensy 4.0, via [MicroROS Agent](https://micro.ros.org/docs/tutorials/core/teensy_with_arduino/) and Arduino support. We can then transition to WiFi based protocol in which we use an ESP32 Wifi chip or RPi Nano chip with builtin wifi and send that to the ground station. We could then possibly use MavLink to send message over radio, which allows multiple drones to communicate with each other.

##### Topics to Publish :
 - `/current_state` : Type (`nav_msgs/odometry)
	 - `geometry_msgs/Twist` : Twist: Current Linear & Angular Velocities
	 - `geometry_msgs/Pose` : Pose: Current Orientation & Position
##### Topics to Subscribe: 
- `/desired_state`  : Type (`trajectory_msgs/MultiDOFJointTrajectoryPoint`)
	- `geometry_msgs/Transform` :  Wanted Position 
		- `Vector3` : Translation: Desired Position
		- `Quaternion` Rotation: Desired Rotation
	- `geometry_msgs/Twist` : Velocities : Desired Linear & Angular Velocities
	- `geometry_msgs/Twist` : Accelerations : Desired Linear & Angular Accelerations
- `/desired_motor_cmds` : Type (`mav_msgs/Actuators`) 
	- `float64[]` Angular Velocities (in RPM)
	
[list2mermaid]

- dRehmFlight_Loop
 - Odometry_Node
	    - /currrent_state
- External_Device
 - Trajectory_Node
		  - /desired_state
 - Motors_Node
		  - /desired_motor_cmds

##### References:
https://micro.ros.org/docs/concepts/middleware/Micro_XRCE-DDS/
https://micro.ros.org/docs/concepts/middleware/memo_prof/
https://mavlink.io/en/about/overview.html

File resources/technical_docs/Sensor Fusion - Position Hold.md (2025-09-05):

Sensors required to get Pose & Twist Data.

[list2pumlWBS]

- Position
	- PWM3901 OpFlow Sensor
	- ST VL53L0X Rangefinder
	- MPU6050 (IMU)
![[Sensor Components.svg | 700x800]]
## Altitude Hold
---------------------------------------------------------------------
### Closed Loop Control

[list2mermaid]

- Handset
	- Target_Altitude_Increase
		- Target_Altitude
			- PID
				- Throttle_Change
					- Target_Altitude_Increase
- Rangefinder
	- Current_Altitude
		- PID
	- Range_Quality
		- PID

The handset gimbal should correlate with movement, i.e. if we move up on the stick the drone should move upwards. *Think of it like* RPY control, the stick is in the middle (0 roll), when we wish to move to the right, we drag the stick to the right, so the roll increases and the drone is angled. When we reach the target location, we let go of the stick, it naturally moves back to the left (to the zero points), so it rolls to the left, just enough to where it levels out, based off of zero desired input, and an unlevel plane.

We can say that midpoint gimbal position = 0 movement, where our throttle = hover throttle, so we need to find out hover throttle first (4 * Tp = mg).

This whole process should act as a PID loop that's cyclical in nature, at each loop iteration. We should get the desired altitude increase which consists of the wanted increase from the handset (i.e 25% up the stick is 2.5mm increase) + the recognized current altitude. This is then compared to the current altitude from the rangefinder. So DV - PV = some error, we can then increase the desired throttle based on this change, as a percentage, so maybe 50% + hover throttle. We should be able to taper off these values, so the closer we are to the target altitude, the less throttle being supplied. *Ensure* there's some form of scaliing

**Empirical** vs **Approximate**? Is it just worth say it's good enough for this case.

#### Caveats:
  - What happens when we leave max/min range?
  - What things affect the motor PWM
  - What do we do when we run into sharp obstacles
  - How do we track hover throttle
  - Create a full blown diagram with the handset, all of the sensors which feeds into a Kalman filter
  - Showcase variation in motor speed with kV

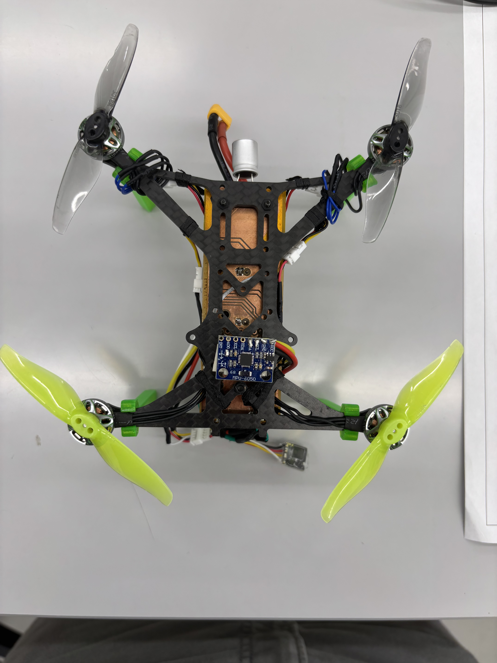
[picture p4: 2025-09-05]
resources/pictures/Top_View_Drone.jpg

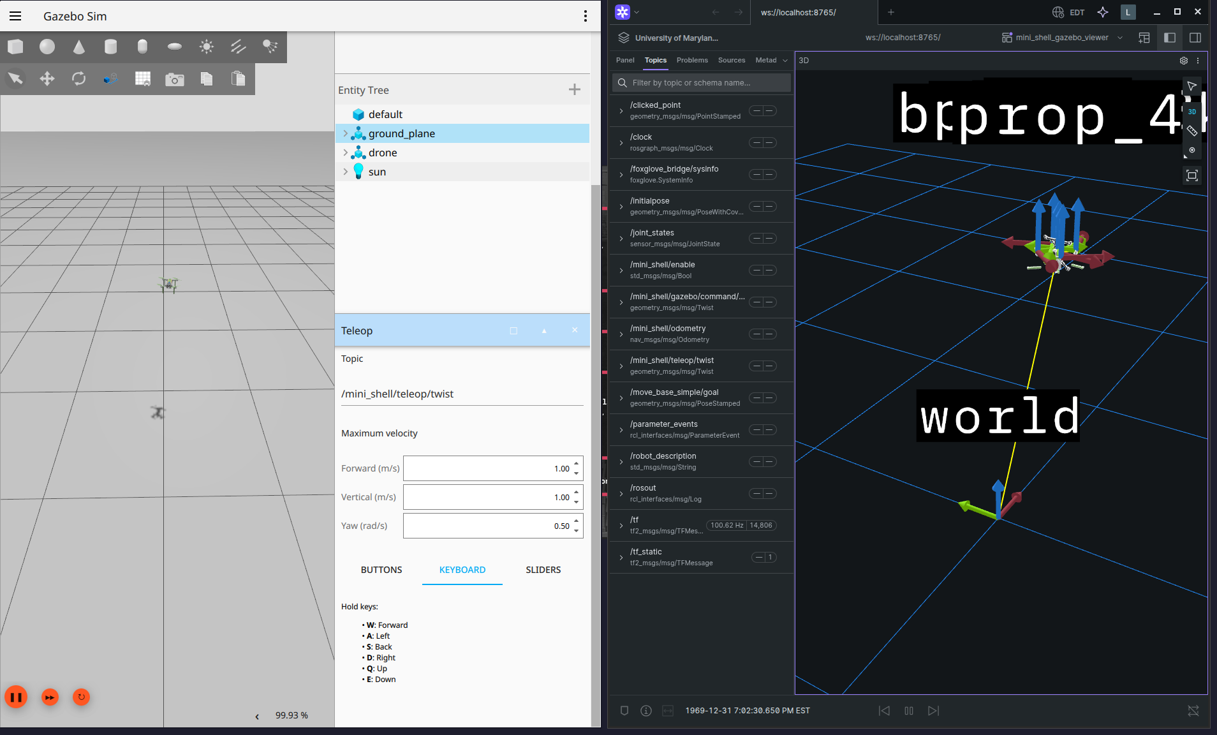
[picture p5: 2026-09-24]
f_drone_simulation/docs/visuals/mini_shell_gz_plug_foxglove_urdf.png

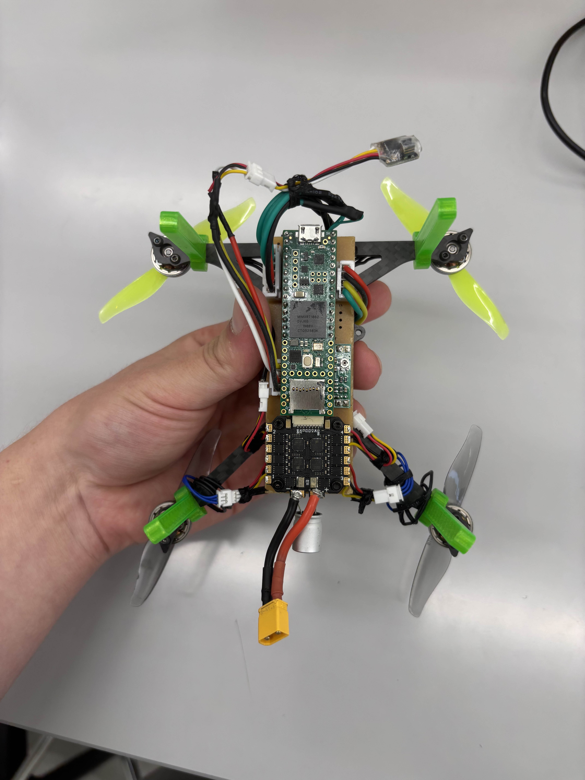
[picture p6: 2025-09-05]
resources/pictures/Bottom_View_Drone.jpg

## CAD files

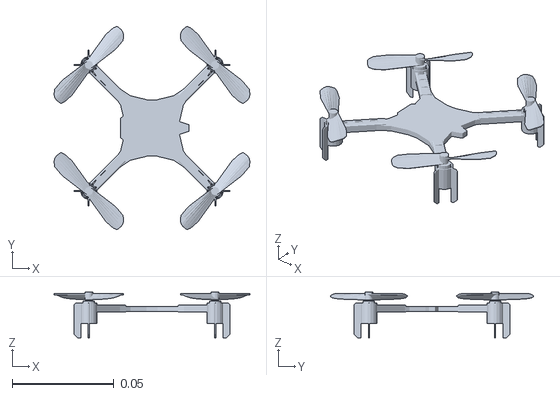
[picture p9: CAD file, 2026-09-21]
f_drone_simulation/f_drone_description/models/crazyflie/meshes/stl_files/cf2_assembly.stl
0.0963 x 0.0998 x 0.0225

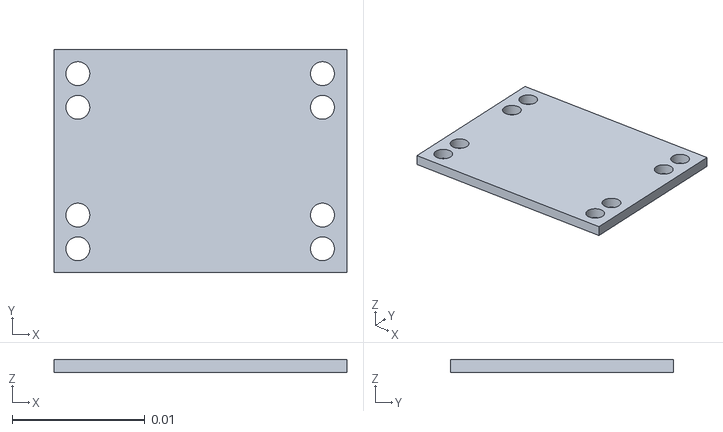
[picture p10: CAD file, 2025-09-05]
f_drone_simulation/f_drone_description/models/f_drone/assets/main001.stl
0.0221 x 0.0168 x 0.00098

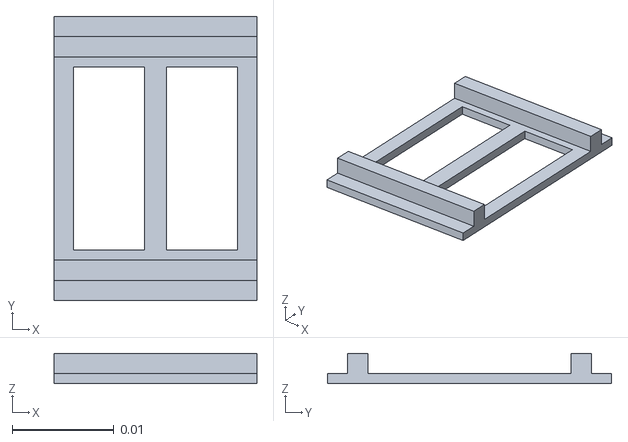
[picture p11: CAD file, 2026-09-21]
f_drone_simulation/f_drone_description/models/crazyflie/meshes/stl_files/battery_holder.stl
0.02 x 0.028 x 0.003

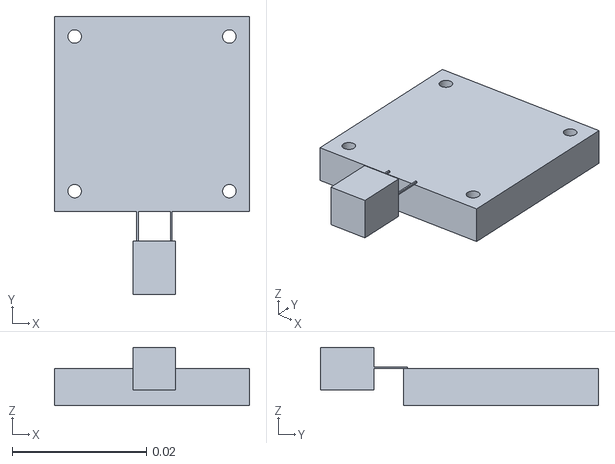
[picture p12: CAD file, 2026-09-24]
f_drone_simulation/f_drone_description/models/drone/meshes/ESC.stl
0.029 x 0.0414 x 0.00865

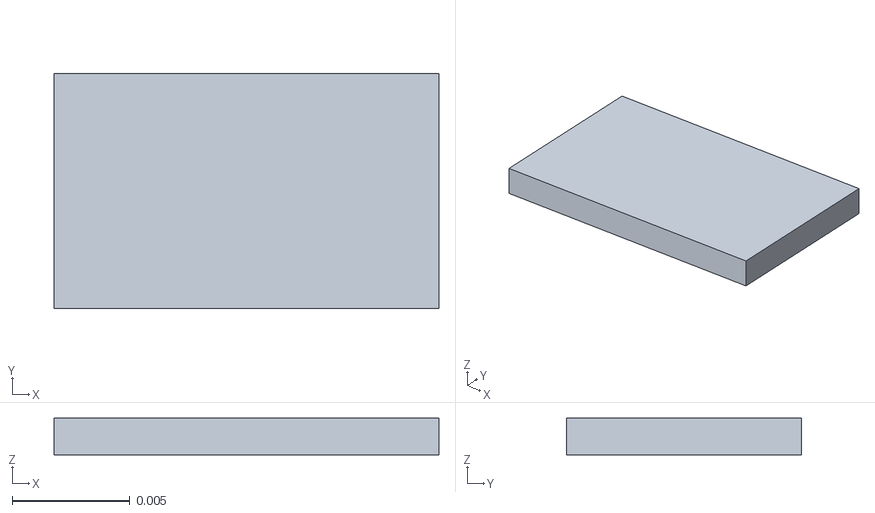
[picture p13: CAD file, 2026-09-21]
f_drone_simulation/f_drone_description/models/f_drone/assets/imu.stl
0.0164 x 0.01 x 0.00157

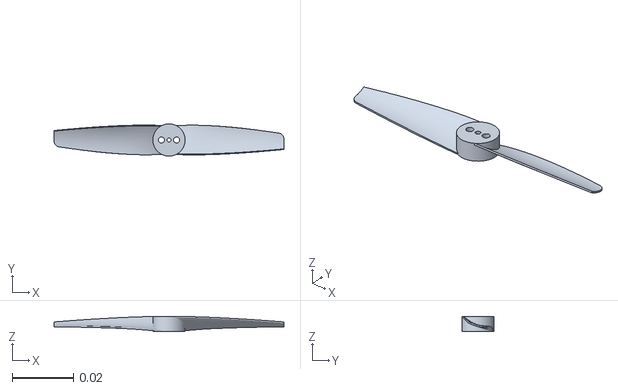
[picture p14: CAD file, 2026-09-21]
f_drone_simulation/f_drone_description/models/mini_shell/assets/prop.stl
0.075 x 0.0105 x 0.005

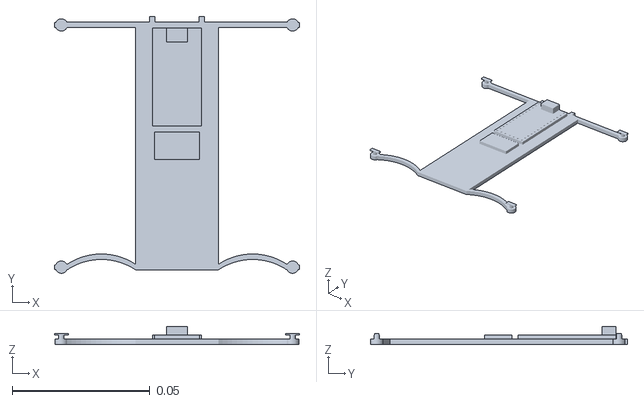
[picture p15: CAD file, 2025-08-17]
Hardware/drone_urdf/assets/merged/center_visual.stl
0.089 x 0.0932 x 0.00664

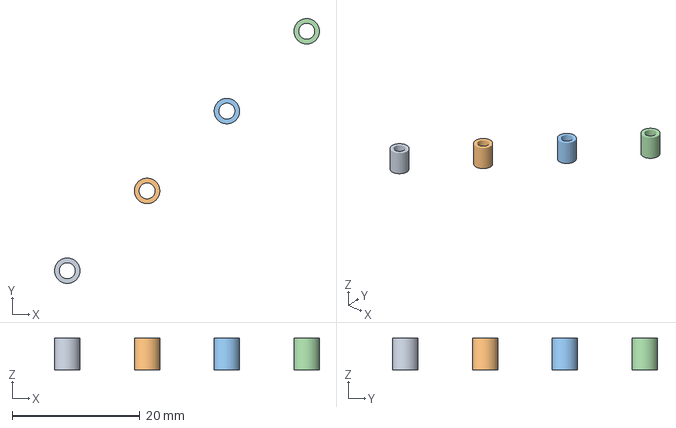
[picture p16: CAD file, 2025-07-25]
Hardware/TeensyCAD/M2Standoff.3mf
41.5 x 41.5 x 5.00 mm

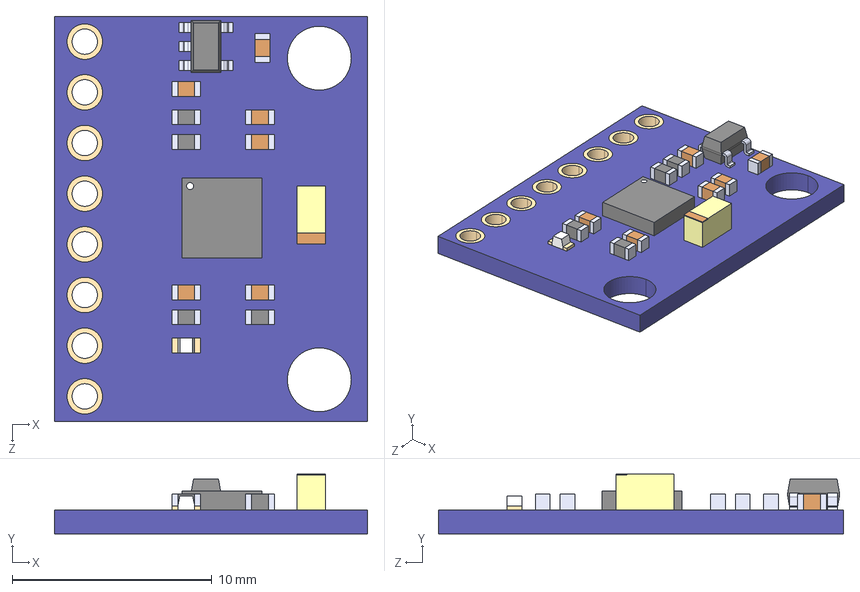
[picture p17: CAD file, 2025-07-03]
Hardware/TeensyDrone/Components/Gy-521/GY-521.step
15.7 x 3.00 x 20.3 mm

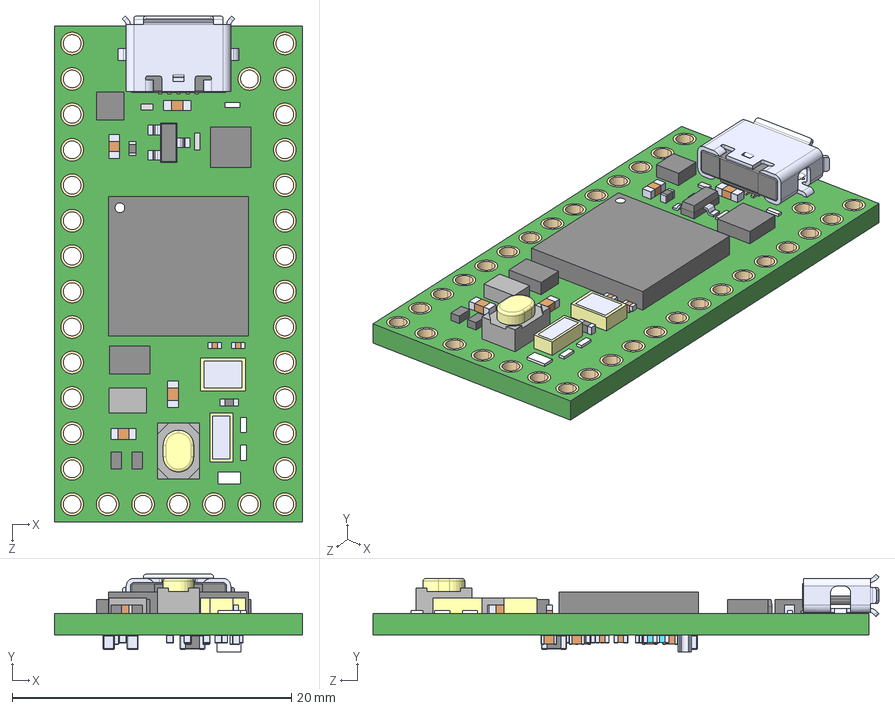
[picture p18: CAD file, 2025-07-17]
Hardware/TeensyDrone/Components/Teensy 4.0/DEV-15583/DEV-15583.step
17.8 x 5.58 x 36.3 mm
DEV-15583 board
C5-C18 (0.55mm)
C20-C24 (0.65)
R1-R3 (0.4inch)_1269AS-H-3R3M=P2
L1^DEV-15583 ASS
C x 2
C2

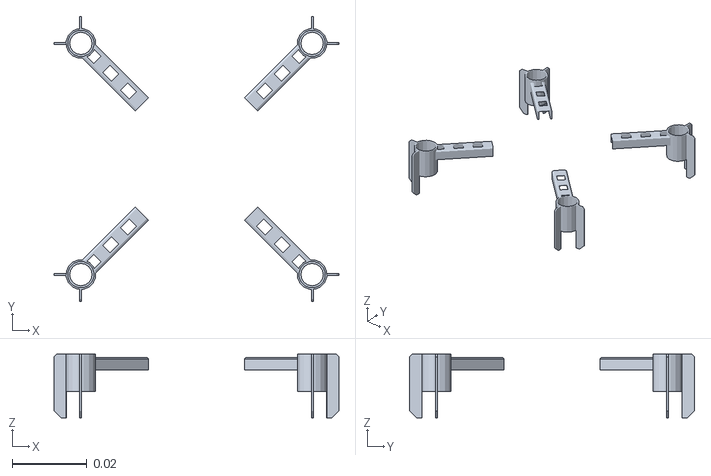
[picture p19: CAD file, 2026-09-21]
f_drone_simulation/f_drone_description/models/crazyflie/meshes/stl_files/4_motormounts.stl
0.0764 x 0.0764 x 0.017

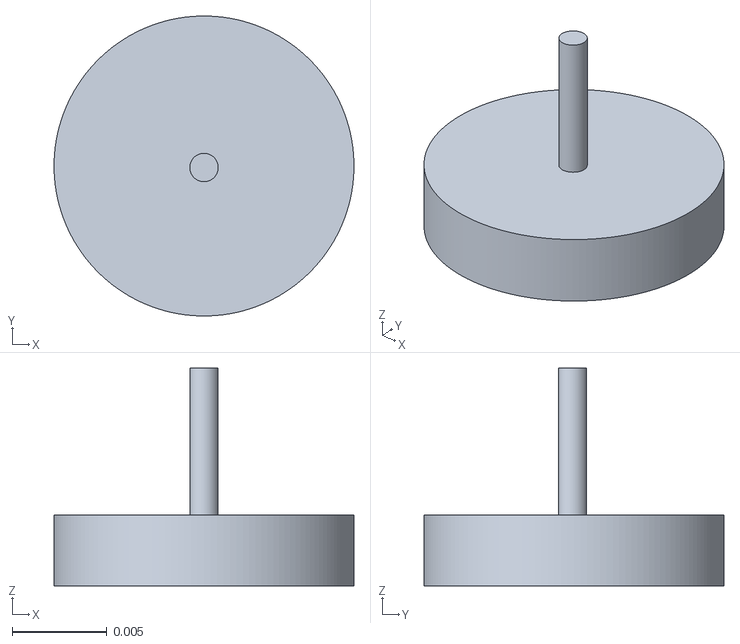
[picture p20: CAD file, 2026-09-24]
f_drone_simulation/f_drone_description/models/drone/meshes/Motor.stl
0.0158 x 0.0158 x 0.0115

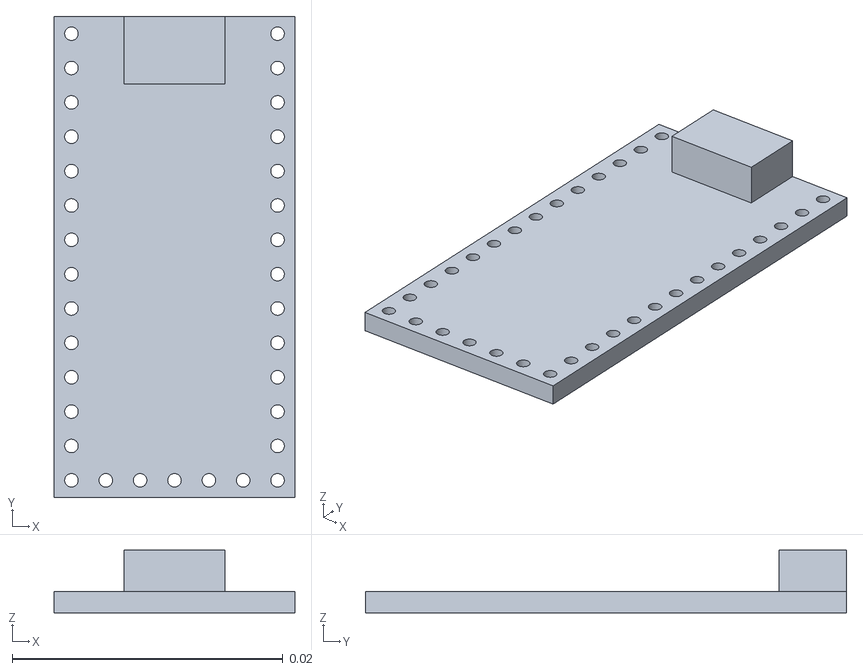
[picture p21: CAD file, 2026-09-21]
f_drone_simulation/f_drone_description/models/f_drone/assets/mcu.stl
0.0178 x 0.0356 x 0.00464

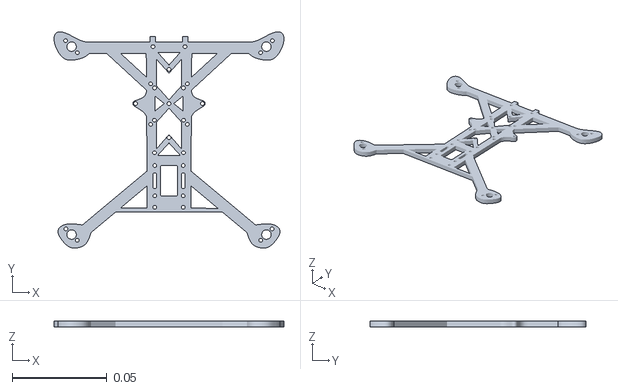
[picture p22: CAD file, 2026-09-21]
f_drone_simulation/f_drone_description/models/mini_shell/assets/base_link.stl
0.121 x 0.114 x 0.003

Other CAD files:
Hardware/TeensyCAD/M2-Standoff-ESC.stl
f_drone_simulation/f_drone_description/models/crazyflie/meshes/stl_files/cf_body.stl
Hardware/TeensyCAD/M2 Standoff(1).stl
Hardware/drone_urdf/assets/2s_battery.stl
Hardware/drone_urdf/assets/custom_pcb.stl
Hardware/drone_urdf/assets/esc.stl
Hardware/drone_urdf/assets/imu.stl
Hardware/drone_urdf/assets/leg.stl
Hardware/drone_urdf/assets/mcu.stl
Hardware/drone_urdf/assets/motor.stl
f_drone_simulation/f_drone_description/models/crazyflie/meshes/blender_files/battery.blend
f_drone_simulation/f_drone_description/models/crazyflie/meshes/blender_files/battery_holder.blend
f_drone_simulation/f_drone_description/models/crazyflie/meshes/blender_files/cf2_assembly.blend
f_drone_simulation/f_drone_description/models/crazyflie/meshes/blender_files/cf_body.blend
f_drone_simulation/f_drone_description/models/crazyflie/meshes/blender_files/cw_prop.blend
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

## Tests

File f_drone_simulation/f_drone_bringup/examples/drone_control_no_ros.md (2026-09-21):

# Drone Control (No ROS) - Hardware in the Loop
-------------------------------------------------
This tutorial will explain the necessary steps of Hardware in the Loop (HIL). HIL is 
a method for higher fiedlity testing a robot, making the onboard computer think that
it's completing actions in the real world, when really we're running in simulation.
Ensure, you have access to a Teensy 4.0/4.1 connected to the ELRS receiver. *Note*,
once we're able to run without the receiver, we won't even need that. You don't need
any other components on the drone as we can find simulated sensor information.

### Running the World
1) Open an instance of the terminal (in the hardware directory).
2) Source your local Gazebo/ROS environment : `source /opt/ros/humble/setup.bash`.
3) Build the simulation package `colcon build && source install/setup.bash`.
4) Run the command ```gz sim worlds/drone_world.sdf``` to open our world.

### Controlling the Drone
1) With the sim up and running, open your Arduino IDE, connect a USB to the Teensy,
upload the code onto the Teensy, then optionally close the IDE.
2) Open another Gazebo-sourced terminal and run the command:

```
gz topic --echo --topic /drone/gazebo/command/motor_speed
```

We can now view the desired velocity (in RPM) of each of our 4 motors.

3) Connect a handset, then feed it stick information.
4) Click play in sim and our drone should be flying around.

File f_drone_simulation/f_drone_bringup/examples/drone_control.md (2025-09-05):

# Drone Control
-------------------------

### Running the World
1) Open an instance of the terminal (in the hardware directory)
2) Source your local ROS environment : `source /opt/ros/humble/setup.bash`
3) Need to also build and source our local packages:
    1) `cd ../FDroneGroundControl`, now build the package: `colcon build`
    2) Navigate back to our local directory `cd ../Simulation` and source that
    previous install `source ../FDroneGroundControl/install/setup.bash`

4) Build the simulation package `colcon build && source install/setup.bash`
5) Run the launch file `ros2 launch f_drone_simulation drone_control.launch.py`
6) Enjoy!

Showing the change of the drone (base_link) to the world frame: 
ros2 run tf2_ros static_transform_publisher --frame-id world --child-frame-id base_link --x 1.0 --y 1.0 --z 1.0

That's like if it were flying, call `ros2 run tf2_tools view_frames` to 
see all active frames in comparison to on another, the only joints are the motors
which we really don't care about right now.

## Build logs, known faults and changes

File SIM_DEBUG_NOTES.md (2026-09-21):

# Simulation Debug Notes — Why the Drone Flips in Gazebo

Date: 2026-07-02/03. Investigation of the "drone flips all around" problem.
Verdict up front: **it is not a CAD problem, not a physics problem, and not a
Gazebo problem. The model is flyable. The bug is a 90° frame-convention
mismatch between the IMU axes and the motor layout in the HIL control path.**

## Evidence (headless Gazebo tests, gz sim 9.5.0)

Test worlds and logs live in the session scratchpad
(`scratchpad/simtest/`): the real `model.sdf` with the DroneSerial/battery/
lidar plugins stripped and nothing else changed physically.

1. **f_drone + MulticopterVelocityControl** (the commented-out plugin block in
   `model.sdf`, enabled as-is): commanded 0.5 m/s climb → rose to 6.45 m and
   held, roll/pitch/yaw flat at 0.00°, zero angular rates for 20 s.
   Identical behavior to the known-good crazyflie run as a positive control.
   ⇒ inertia tensor, motor constants, spin directions, prop placement are all
   consistent and flyable.

2. **f_drone open loop**: published the firmware's "+roll" actuator pattern
   (actuators 0,1 faster than 2,3 — what dRehmFlight thinks are the two LEFT
   motors) → the body rotated purely about **+y** (mean ω_y ≈ 1.63 rad/s,
   ω_x ≈ ω_z ≈ 0) and flipped inverted within ~2 s.
   dRehmFlight damps roll with GyroX — which never moved. That is the flip.

## Root cause, in full

- The OnShape export placed the drone's **forward axis along SDF +y**
  (rangefinder at y=+0.055 is the nose, ESC/battery cables at −y are the
  back). The inertia corroborates it: ixx (2.60e-4) ≈ 3× iyy (0.83e-4)
  because the heavy components are strung along y.
- The dRehmFlight mixer numbering (`controlMixer()`, dRehmFlight.ino:819-838:
  1=Front-Left, 2=Back-Left, 3=Front-Right, 4=Back-Right) maps **perfectly**
  onto prop_1..prop_4 positions *if* front=+y and left=−x:
  | firmware motor | corner | SDF prop | position (x, y) | spin |
  |---|---|---|---|---|
  | 1 (pwm[0], actuator 0) | Front-Left  | prop_1 | (−0.051, +0.050) | cw |
  | 2 (pwm[1], actuator 1) | Back-Left   | prop_2 | (−0.051, −0.050) | ccw |
  | 3 (pwm[2], actuator 2) | Front-Right | prop_3 | (+0.051, +0.050) | ccw |
  | 4 (pwm[3], actuator 3) | Back-Right  | prop_4 | (+0.051, −0.050) | cw |
  (Diagonal pairs match, and the yaw mixing signs are consistent with these
  spin directions — the motor table itself is correct.)
- **But** the Gazebo IMU sensor reports accel/gyro in the *link frame*, where
  x is the drone's *right side*, not its front. dRehmFlight assumes the IMU
  x-axis is forward (that's the physical MPU6050 mounting convention its
  Madgwick sign flips are built for). DroneSerial.cpp forwards the IMU
  axes raw. Net effect: the firmware's roll axis is physically the pitch
  axis and vice versa. Roll error produces pitch motion → PID loops are fully
  cross-coupled → guaranteed tumble. Confirmed empirically by test 2 above.

## The fix (pick ONE, not several)

**Recommended: rotate the IMU sensor frame in `model.sdf` by +90° yaw** so the
virtual IMU is "mounted" the way dRehmFlight expects (x = forward):

```xml
<sensor name="imu_sensor" type="imu">
  <pose>0 0 0 0 0 1.5708</pose>
  ...
```

Sensor x then points at link +y (front), sensor y at link −x (left), z up —
the MPU6050 x-forward/y-left/z-up convention. With that, all three loops
close with the correct sign (checked analytically: +roll_PID → left motors
faster → +GyroX in sensor frame → damped; pitch and yaw likewise).

Alternatives (equivalent, more invasive): re-export the CAD with x-forward so
the whole link frame rotates, or remap the actuator order in
DroneSerial::pwmToVelocity. Doing more than one of these re-breaks it.

**Bench check for the real drone:** the same constraint applies to hardware —
the physical MPU6050 chip x-axis must point at the front (between motors 1
and 3, away from the battery cables). If HIL was flipping but the real drone
flew, the physical chip is mounted correctly and only the sim IMU frame was
wrong.

## Secondary findings (not the flip, but worth fixing)

1. **DroneSerial crashes Gazebo when no Teensy is plugged in.**
   `initializeSerialPort` (DroneSerial.cpp:243-300): if `open()` fails it
   only prints, then calls `flock(-1, ...)` which fails → throws
   `std::runtime_error`. Should return early after a failed open.
2. **Duplicate OdometryPublisher** plugin instances in `model.sdf` (lines
   ~457 and ~587) — both publish to `/model/drone/odometry`.
3. The IMU `<orientation_reference_frame>` block mixes `NWU` localization
   with `grav_dir_x` (model.sdf:123-127). Currently harmless because the
   firmware only consumes accel/gyro (never the orientation quaternion), but
   it's confusing — and the comment in `getIMUdataSim` claiming Gazebo data
   is "NWD" is wrong: the Gazebo IMU is z-up, +9.81 on z at rest, same as a
   flat-mounted MPU6050. Units conversion there (m/s²→g, rad/s→deg/s) is
   correct.
4. **Real pitch/roll inertia asymmetry**: ixx ≈ 3× iyy is *real* (mass along
   y). After the frame fix, expect the roll axis (about body-front) to be 3×
   more agile than pitch — per-axis PID gains will likely need to differ.
   The commented-out `*1.1926` boost hack in `pwmToVelocity` (DroneSerial
   .cpp:346-347) was probably compensating for a symptom of the frame bug —
   delete it.
5. Thrust budget sanity (all fine): hover ≈ 341 rad/s (sim units) ≈ PWM 213;
   kv mapping in pwmToVelocity caps at ≈ 483 rad/s < maxRotVelocity 600 →
   thrust/weight ≈ 2.0. The `kv = 11000/20` correctly bakes in
   `rotorVelocitySlowdownSim=20`.
6. DroneAutoSim.cpp forwards IMU axes raw and maps pwm[i]→actuator i just
   like DroneSerial, so it needs no change once the IMU sensor pose is fixed
   (and would have needed the same fix otherwise).

## Build environment (added 2026-07-08)

`colcon build` with Jazzy sourced failed on `find_package(gz-common)` because
this machine has THREE Gazebo stacks: system Harmonic debs (gz-sim8), system
Ionic debs (gz-sim9 — what the bare `gz sim` CLI runs), and ROS Jazzy's
vendored Harmonic under `/opt/ros/jazzy/opt/` (what `ros_gz_sim` launches).
Unversioned gz-* CMake names only exist in the vendor packages' `extra_cmake`
dirs, which are visible only after `find_package(gz_*_vendor)`.

Fixed in `f_drone_simulation/CMakeLists.txt` by finding the `gz_*_vendor`
packages before the `gz-*` ones. Verified: build succeeds and `ldd` shows all
three plugins linking the vendored libs — the same gz-sim8 that ros_gz_sim
runs, which is what matters for plugin load-time ABI compatibility.

Follow-ups worth doing:
- `f_drone_simulation/README.md:11-13` says ROS Humble + Gazebo Ionic; the
  branch is `humble`; the CMakeLists targets Harmonic via Jazzy vendors.
  Reconcile the docs to the real setup: **ROS Jazzy + vendored Harmonic**.
- Declare the `gz_*_vendor` packages in `package.xml` so rosdep/CI installs
  them.
- Plugins built against gz-sim8 will NOT load in the bare `gz sim` CLI
  (Ionic/gz-sim9). Launch through ros_gz_sim, or run
  `/opt/ros/jazzy/opt/gz_sim_vendor/bin/gz sim` explicitly.

## Ogre2 segfault in quadcopter_teleop.sdf (added 2026-07-09)

`gz sim worlds/quadcopter_teleop.sdf` crashed in
`SensorsPrivate::RenderThread` (segfault or Ogre `createDatablock` abort,
varies by timing). Cause: the **Sensors system was loaded twice** — once at
world level (quadcopter_teleop.sdf) and once inside the included
`backup_model.sdf`. Two instances race to create the same ogre2 scene/
materials. Fixed by removing the world-level copy; the drone models in this
repo are self-contained and carry their own Sensors system (the HIL and
autonomous worlds depend on that). Verified: server runs cleanly after.

Rule of thumb for this repo: a world must end up with **exactly one** Sensors
system after all includes. `crazyflie.sdf` and `real.sdf` keep theirs at
world level because their models don't carry one; any world that includes
`model.sdf`/`backup_model.sdf`/`blank.sdf` must NOT declare it.

## backup_model.sdf vs model.sdf (added 2026-07-09)

**`model.sdf` is the real drone.** `backup_model.sdf` is a stale draft carrying
x500-scale parameters: motorConstant 8.54858e-06, momentConstant 0.016, and —
fatally — base_link inertia ixx=iyy=3.95e-3 / izz=7.5e-3, a ~14 cm radius of
gyration on a 10 cm airframe. Physically impossible; the velocity controller
saturates the rotors trying to meet inertia-scaled moment demands and the
drone just skids and yaw-spins on the ground. Verified empirically: identical
controller + world flies model.sdf perfectly and cannot lift backup_model.

Changes made for Teensy-free flying:
- `worlds/quadcopter_teleop.sdf` now includes `model.sdf` (not backup_model).
- `model.sdf`: DroneSerial commented out (uncomment for HIL — note
  `drone_world_hil.sdf` needs it), MulticopterVelocityControl active.
- `backup_model.sdf` also got a (correctly configured) velocity controller
  block, but the model cannot fly until its inertia is fixed — treat the file
  as deprecated.

Verified headless on `worlds/quadcopter_teleop.sdf`: enable → climb 0.5 m/s
→ zero-twist hold: reached 5.52 m, 15 s hold with zero drift, level attitude,
spawn yaw held. Recipe:
```
gz topic -t /drone/enable  -m gz.msgs.Boolean -p 'data: true'
gz topic -t /drone/cmd_vel -m gz.msgs.Twist   -p 'linear: {z: 0.5}'
```
`/drone/gazebo/command/motor_speed` (gz.msgs.Actuators) also works, but only
with the controller left disabled — both write the same motor commands.

Minor: the world's physics block is named "2000hz" but max_step_size is
0.005 s (200 Hz). Flight is stable anyway; rename or set 0.0005 for honesty.

### Manual stress test (user, 2026-07-09)

Using the Teleop GUI plugin on `/drone/cmd_vel`, commanded 10 m/s forward
(well outside the small-angle regime `velocityGain`/`attitudeGain` were
tuned for) to deliberately force a crash and rule out the physics quietly
clamping/no-op'ing instead of actually being pushed to its limit. Result:
drone lost control and crashed — confirmed by the user to look physically
correct (attitude tumble, not a teleport/clip-through-ground/frozen-state
artifact). This is a second, independent confirmation (alongside the
position-hold test above) that the airframe, inertia, and collision
geometry in `model.sdf` are all sound — the failure mode is the controller
saturating at an unreasonable command, not a bug.

Follow-up if the flight envelope matters later: find the highest commanded
velocity that still holds a stable trajectory before tipping into
uncontrolled tumble, rather than just the point of total failure.

## backup_model.sdf: real per-part collision ported into model.sdf, backup left broken (2026-08-04)

Revisited the "model.sdf vs backup_model.sdf" call above after being shown
side-by-side renders. Correction to that entry: **the "perfectly balanced
variant" read on model.sdf was wrong.** Diffed both files link-by-link:
same STL meshes, same mass (0.2035 kg), sub-millimeter pose differences
consistent with two export passes of the *same* CAD assembly, not a
redesign. There is no balanced-vs-true-asymmetric distinction. The x500-scale
inertia call from before stands — that part was real.

What backup_model.sdf actually has that model.sdf didn't: real per-part
collision meshes (18, one for the frame deck + one per motor/leg/battery/PCB/
ESC/MCU/IMU) instead of model.sdf's single crude bounding box. That's a
genuine fidelity advantage worth keeping.

Fixed backup_model.sdf's inertia (copied model.sdf's tensor, same geometry)
and motor constants (x500 template → model.sdf's tuned values, same as
before) and it *still* produced exactly zero joint response to any actuator
command — confirmed via `/world/.../model/drone/joint_state`, angular
velocity ~1e-20 rad/s regardless of commanded speed (0 to 450 rad/s tested).
Isolated one variable at a time, all ruled out, no change in any case:
- real STL collision vs. simplified box collision
- `timeConstantUp`/`timeConstantDown` (present in backup, absent in model.sdf)
- the motor plugin XML itself (swapped in model.sdf's exact working block,
  retargeted to backup's joint/link names)
- `pose relative_to=` chaining vs. model.sdf's absolute-pose convention

Topic wiring confirmed correct (`gz topic -i` shows all 4 motor plugins
subscribed) and the file passes `gz sdf -k`. Root cause not found — something
in backup_model.sdf's structure silently prevents the physics engine from
applying joint velocity commands, independent of every difference tried.
**Do not spend more time on backup_model.sdf directly without a new lead;**
this was a thorough elimination pass, not a shallow one.

Pragmatic resolution: ported backup_model.sdf's real per-part collision
meshes into model.sdf (the file that actually works), rather than continuing
to debug backup's dead joints. Script: session scratchpad
`simtest/add_real_collisions.py`. Change: `model.sdf`'s single
`0.1029x0.09925x0.10` bounding box collision shrunk to a `0.105x0.105x0.003`
deck-plate box (`base_link_deck_collision`), plus 13 new `<collision>`
elements added — one per mounted-part visual (legs, motors, battery, MCU,
IMU, custom PCB, ESC), each using the same mesh and pose as its matching
visual. The main frame mesh (base_link.stl) is intentionally *not* used
directly as collision, matching backup_model.sdf's own choice to box the
deck rather than collide against that mesh raw.

Verified headless on the same climb/hold recipe as above: reached 5.53 m,
held with zero drift, dead-level attitude — statistically identical to the
pre-change box-collision result (5.52 m). `backup_model.sdf` is now
redundant; `model.sdf` has both the correct physics and the real collision
fidelity. Treat `backup_model.sdf` as dead/do-not-use going forward — it has
an unresolved bug that prevents any motor command from producing joint
motion, on top of already being superseded by this port.

## How to re-verify after the fix

1. Headless regression (no Teensy): the velocity-control world in the
   scratchpad, or equivalently uncomment MulticopterVelocityControl —
   should still climb/hover level (the frame fix doesn't touch physics).
2. HIL smoke test: with the Teensy attached, command pure roll from the
   firmware and confirm the sim rotates about the axis the firmware calls
   roll (GyroX response, not GyroY); then pitch; then yaw. Then attempt
   hover.

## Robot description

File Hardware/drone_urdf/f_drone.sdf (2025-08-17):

<sdf version='1.11'>
  <model name='Hardware'>
    <link name='basic_link'>
      <inertial>
        <pose>0.00010427799999999999 0.0045317700000000001 0.00047249999999999999 0 0 0</pose>
        <mass>0.0099244899999999994</mass>
        <inertia>
          <ixx>7.2680599999999997e-06</ixx>
          <ixy>2.97785e-23</ixy>
          <ixz>-1.19941e-23</ixz>
          <iyy>1.3417e-06</iyy>
          <iyz>-8.7168500000000004e-08</iyz>
          <izz>8.5867399999999997e-06</izz>
        </inertia>
      </inertial>
      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
    </link>
    <joint name='motor_prop_1' type='revolute'>
      <pose relative_to='basic_link'>0.042104299999999997 0.043042299999999999 0.00247314 3.1415899999999999 0 0</pose>
      <parent>basic_link</parent>
      <child>propeller_2</child>
      <axis>
        <xyz>0 0 1</xyz>
        <limit>
          <lower>-3.1415926535897931</lower>
          <upper>3.1415926535897931</upper>
          <effort>10</effort>
          <velocity>10</velocity>
        </limit>
        <dynamics>
          <spring_reference>0</spring_reference>
          <spring_stiffness>0</spring_stiffness>
        </dynamics>
      </axis>
    </joint>
    <link name='propeller_2'>
      <pose relative_to='motor_prop_1'>0 0 0 0 0 0</pose>
      <inertial>
        <pose>-6.0117399999999996e-20 -2.3995200000000001e-18 -0.00025000000000000001 0 0 0</pose>
        <mass>5.4687499999999999e-06</mass>
        <inertia>
          <ixx>1.0000000000000001e-09</ixx>
          <ixy>0</ixy>
          <ixz>0</ixz>
          <iyy>1.0000000000000001e-09</iyy>
          <iyz>0</iyz>
          <izz>1.0000000000000001e-09</izz>
        </inertia>
      </inertial>
      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
    </link>
    <joint name='motor_prop_2' type='revolute'>
      <pose relative_to='basic_link'>0.042104299999999997 -0.044957700000000003 0.00247314 3.1415899999999999 0 0</pose>
      <parent>basic_link</parent>
      <child>propeller</child>
      <axis>
        <xyz>0 0 1</xyz>
        <limit>
          <lower>-3.1415926535897931</lower>
          <upper>3.1415926535897931</upper>
          <effort>10</effort>
          <velocity>10</velocity>
        </limit>
        <dynamics>
          <spring_reference>0</spring_reference>
          <spring_stiffness>0</spring_stiffness>
        </dynamics>
      </axis>
    </joint>
    <link name='propeller'>
      <pose relative_to='motor_prop_2'>0 0 0 0 0 0</pose>
      <inertial>
        <pose>-6.0117399999999996e-20 -2.3995200000000001e-18 -0.00025000000000000001 0 0 0</pose>
        <mass>5.4687499999999999e-06</mass>
        <inertia>
          <ixx>1.0000000000000001e-09</ixx>
          <ixy>0</ixy>
          <ixz>0</ixz>
          <iyy>1.0000000000000001e-09</iyy>
          <iyz>0</iyz>
          <izz>1.0000000000000001e-09</izz>
        </inertia>
      </inertial>
      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
    </link>
    <joint name='motor_prop_3' type='revolute'>
      <pose relative_to='basic_link'>-0.041895700000000001 0.043042299999999999 0.00247314 3.1415899999999999 -7.9409288317992723e-23 1.4220299999999999e-07</pose>
      <parent>basic_link</parent>
      <child>propeller_3</child>
      <axis>
        <xyz>0 0 1</xyz>
        <limit>
          <lower>-3.1415926535897931</lower>
          <upper>3.1415926535897931</upper>
          <effort>10</effort>
          <velocity>10</velocity>
        </limit>
        <dynamics>
          <spring_reference>0</spring_reference>
          <spring_stiffness>0</spring_stiffness>
        </dynamics>
      </axis>
    </joint>
    <link name='propeller_3'>
      <pose relative_to='motor_prop_3'>0 0 0 0 0 0</pose>
      <inertial>
        <pose>-6.0117399999999996e-20 -2.3995200000000001e-18 -0.00025000000000000001 0 0 0</pose>
        <mass>5.4687499999999999e-06</mass>
        <inertia>
          <ixx>1.0000000000000001e-09</ixx>
          <ixy>3.44551e-34</ixy>
          <ixz>1.6807799999999999e-49</ixz>
          <iyy>1.0000000000000001e-09</iyy>
          <iyz>-6.7632999999999998e-50</iyz>
          <izz>1.0000000000000001e-09</izz>
        </inertia>
      </inertial>
      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
    </link>
    <joint name='motor_prop_4' type='revolute'>
      <pose relative_to='basic_link'>-0.041895700000000001 -0.044957700000000003 0.00247314 3.1415899999999999 0 0</pose>
      <parent>basic_link</parent>
      <child>propeller_4</child>
      <axis>
        <xyz>0 0 1</xyz>
        <limit>
          <lower>-3.1415926535897931</lower>
          <upper>3.1415926535897931</upper>
          <effort>10</effort>
          <velocity>10</velocity>
        </limit>
        <dynamics>
          <spring_reference>0</spring_reference>
          <spring_stiffness>0</spring_stiffness>
        </dynamics>
      </axis>
    </joint>
    <link name='propeller_4'>
      <pose relative_to='motor_prop_4'>0 0 0 0 0 0</pose>
      <inertial>
        <pose>-6.0117399999999996e-20 -2.3995200000000001e-18 -0.00025000000000000001 0 0 0</pose>
        <mass>5.4687499999999999e-06</mass>
        <inertia>
          <ixx>1.0000000000000001e-09</ixx>
          <ixy>0</ixy>
          <ixz>0</ixz>
          <iyy>1.0000000000000001e-09</iyy>
          <iyz>0</iyz>
          <izz>1.0000000000000001e-09</izz>
        </inertia>
      </inertial>
      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
    </link>
  </model>
</sdf>

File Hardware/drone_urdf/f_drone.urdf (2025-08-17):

<?xml version="1.0" ?>
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
<robot name="Hardware">
  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
  <link name="basic_link">
    <inertial>
      <origin xyz="0.000104278 0.00453177 0.0004725" rpy="0 0 0"/>
      <mass value="0.00992449"/>
      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
    </inertial>
    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
  </link>
  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
  <link name="propeller">
    <inertial>
      <origin xyz="-6.01174e-20 -2.39952e-18 -0.00025" rpy="0 0 0"/>
      <mass value="5.46875e-06"/>
      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
    </inertial>
    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
  </link>
  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
  <joint name="motor_prop_2" type="revolute">
    <origin xyz="0.0421043 -0.0449577 0.00247314" rpy="3.14159 -0 0"/>
    <parent link="basic_link"/>
    <child link="propeller"/>
    <axis xyz="0 0 1"/>
    <limit effort="10" velocity="10" lower="-3.141592653589793" upper="3.141592653589793"/>
  </joint>
  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
  <link name="propeller_2">
    <inertial>
      <origin xyz="-6.01174e-20 -2.39952e-18 -0.00025" rpy="0 0 0"/>
      <mass value="5.46875e-06"/>
      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
    </inertial>
    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
  </link>
  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
  <joint name="motor_prop_1" type="revolute">
    <origin xyz="0.0421043 0.0430423 0.00247314" rpy="3.14159 -0 0"/>
    <parent link="basic_link"/>
    <child link="propeller_2"/>
    <axis xyz="0 0 1"/>
    <limit effort="10" velocity="10" lower="-3.141592653589793" upper="3.141592653589793"/>
  </joint>
  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
  <link name="propeller_3">
    <inertial>
      <origin xyz="-6.01174e-20 -2.39952e-18 -0.00025" rpy="0 0 0"/>
      <mass value="5.46875e-06"/>
      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
    </inertial>
    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
  </link>
  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
  <joint name="motor_prop_3" type="revolute">
    <origin xyz="-0.0418957 0.0430423 0.00247314" rpy="3.14159 -7.94093e-23 1.42203e-07"/>
    <parent link="basic_link"/>
    <child link="propeller_3"/>
    <axis xyz="0 0 1"/>
    <limit effort="10" velocity="10" lower="-3.141592653589793" upper="3.141592653589793"/>
  </joint>
  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
  <link name="propeller_4">
    <inertial>
      <origin xyz="-6.01174e-20 -2.39952e-18 -0.00025" rpy="0 0 0"/>
      <mass value="5.46875e-06"/>
      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
    </inertial>
    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
  </link>
  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
  <joint name="motor_prop_4" type="revolute">
    <origin xyz="-0.0418957 -0.0449577 0.00247314" rpy="3.14159 -0 0"/>
    <parent link="basic_link"/>
    <child link="propeller_4"/>
    <axis xyz="0 0 1"/>
    <limit effort="10" velocity="10" lower="-3.141592653589793" upper="3.141592653589793"/>
  </joint>
</robot>

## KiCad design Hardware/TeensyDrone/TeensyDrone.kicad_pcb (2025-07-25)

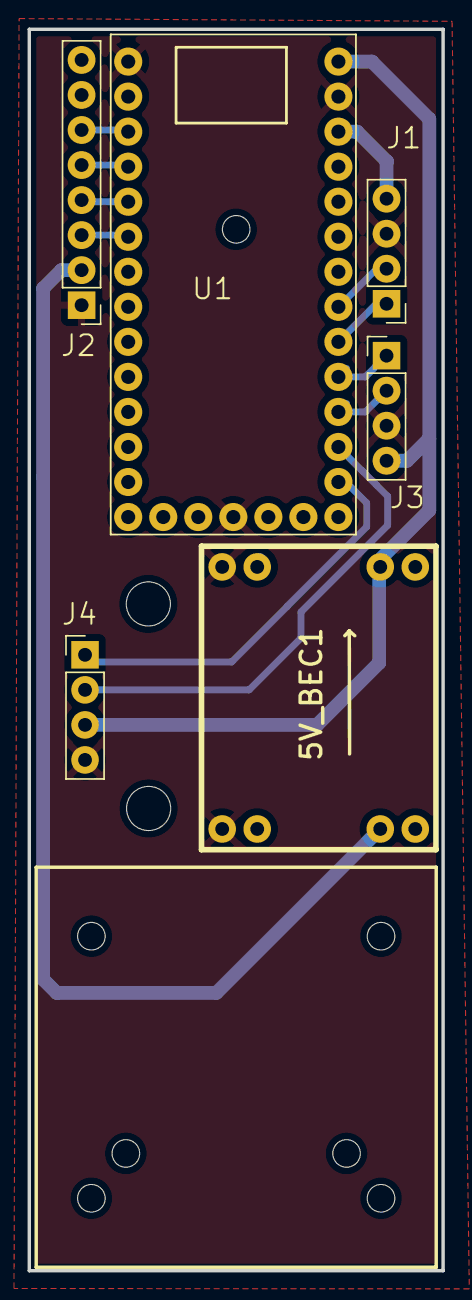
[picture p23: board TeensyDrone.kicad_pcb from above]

Board: 2 copper layers, 30.0 x 90.0 mm, 15 parts (0 on the bottom side), 14 nets.

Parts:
5V_BEC1: 5V_BEC
H1, H2, H3, H5, H6, H7, H8: MountingHole; MountingHole_2mm
H9, H11: MountingHole; MountingHole_3.2mm_M3
J1, J3, J4: Conn_01x04; PinHeader_1x04_P2.54mm_Vertical
J2: Conn_01x08; PinHeader_1x08_P2.54mm_Vertical
U1: DEV-15583; MODULE_DEV-15583

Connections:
5V: 5V_BEC1.7 (5V), J3.4 (5V), J4.3 (SCL), U1.VIN
+3.3V: J1.4 (SDA), U1.3.3V (3.3)
ELRS_RX: J4.1 (3.3V), U1.14
ELRS_TX: J4.2 (GND), U1.15
GND: 5V_BEC1.1 (GND), 5V_BEC1.5 (GND), J1.3 (SCL), J2.1, J3.3 (GND), J4.4 (SDA), U1.G1 (GND), U1.G2 (GND), U1.G3 (GND)
IMU_SCL: J1.2 (GND), U1.19
IMU_SDA: J1.1 (3.3V), U1.18
unnamed: J2.3, U1.4
unnamed: J2.4, U1.3
unnamed: J2.5, U1.2
unnamed: J2.6, U1.1
OF_RX: J3.1 (RX), U1.17
OF_TX: J3.2 (TX), U1.16
VBat: 5V_BEC1.3 (VBat), J2.2

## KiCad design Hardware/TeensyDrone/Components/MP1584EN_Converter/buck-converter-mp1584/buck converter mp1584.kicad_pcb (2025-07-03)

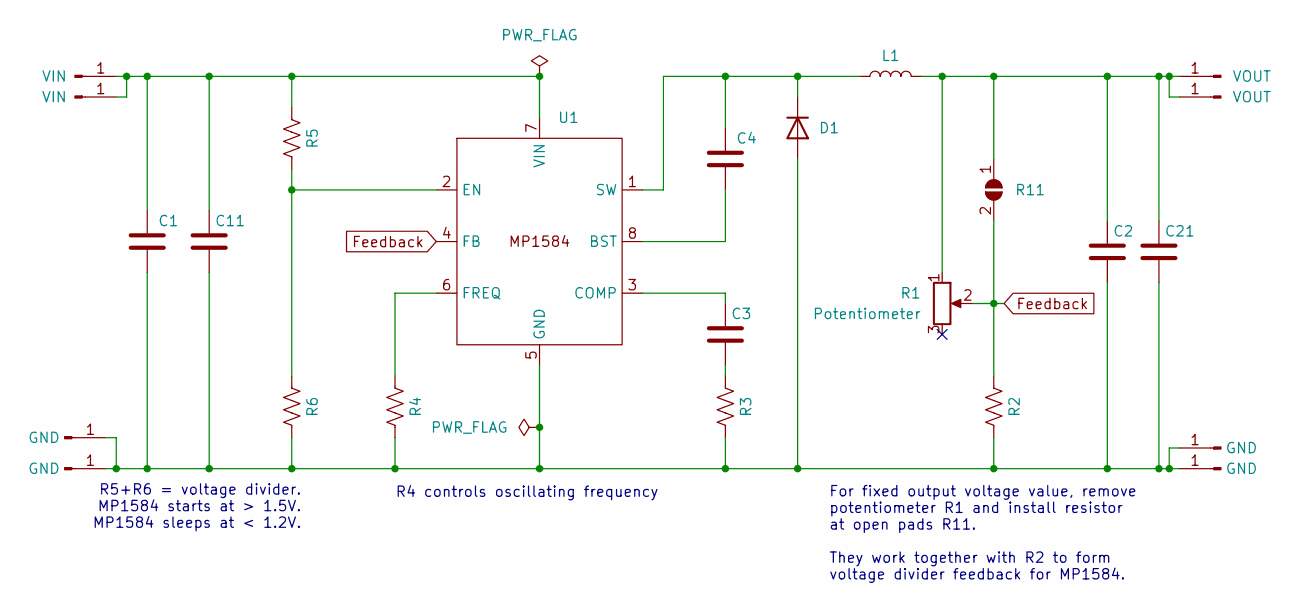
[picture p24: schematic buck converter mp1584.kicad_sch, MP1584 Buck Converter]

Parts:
C1, C2: C; C_0805_2012Metric
C3, C4, C11, C21: C; C_0201_0603Metric
D1: D; D_0805_2012Metric
J1, J6: VIN; PinHeader_1x01_P1.00mm_Vertical
J2, J4, J5, J7: GND; PinHeader_1x01_P1.00mm_Vertical
J3, J8: VOUT; PinHeader_1x01_P1.00mm_Vertical
L1: L; L_Neosid_SM-PIC0512H
R1: Potentiometer; Potentiometer_ACP_CA6-H2,5_Horizontal
R2, R3, R4, R5, R6: R_US; R_0201_0603Metric
R11: SolderJumper_2_Open; SolderJumper-2_P1.3mm_Open_Pad1.0x1.5mm
U1: MP1584EN

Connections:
Feedback: R1.2, R2.1, R11.2 (B), U1.4 (FB)
unnamed: C3.2, R3.1
unnamed: C1.2, C2.2, C11.2, C21.2, D1.2 (A), J2.1, J4.1, J5.1, J7.1, R2.2, R3.2, R4.2, R6.2, U1.5 (GND)
unnamed: C4.1, D1.1 (K), L1.1, U1.1 (SW)
unnamed: C1.1, C11.1, J1.1, J6.1, R5.1, U1.7 (VIN)
unnamed: C2.1, C21.1, J3.1, J8.1, L1.2, R1.1, R11.1 (A)
unnamed: C4.2, U1.8 (BST)
unnamed: C3.1, U1.3 (COMP)
unnamed: R5.2, R6.1, U1.2 (EN)
unnamed: R4.1, U1.6 (FREQ)

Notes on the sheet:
R4 controls oscillating frequency
For fixed output voltage value, remove potentiometer R1 and install resistor at open pads R11. They work together with R2 to form voltage divider feedback for MP1584.
R5+R6 = voltage divider. MP1584 starts at > 1.5V. MP1584 sleeps at < 1.2V.

Board: 2 copper layers, 24 parts (0 on the bottom side), 10 nets, no tracks yet.

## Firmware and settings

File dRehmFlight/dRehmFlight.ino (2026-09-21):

//Arduino/Teensy Flight Controller - dRehmFlight
//Author: Nicholas Rehm
//Project Start: 1/6/2020
//Last Updated: 7/29/2022
//Version: Beta 1.3

//========================================================================================================================//

//CREDITS + SPECIAL THANKS
/*
Some elements inspired by:
http://www.brokking.net/ymfc-32_main.html
x
Madgwick filter function adapted from:
https://github.com/arduino-libraries/MadgwickAHRS

Thank you to:
RcGroups 'jihlein' - IMU implementation overhaul + SBUS implementation.
Everyone that sends me pictures and videos of your flying creations! -Nick

*/
//========================================================================================================================//
//                                                 USER-SPECIFIED DEFINES                                                 //
//========================================================================================================================//

// Uncomment only one receiver type
//#define USE_PWM_RX
//#define USE_PPM_RX
//#define USE_SBUS_RX
//#define USE_DSM_RX
#define USE_CRSF_RX
static const uint8_t num_DSM_channels = 6; //If using DSM RX, change this to match the number of transmitter channels you have

#define USE_MPU6050_I2C  // Default
#define USE_MATEK3901    // Default

//========================================================================================================================//

// REQUIRED LIBRARIES (included with download in main sketch folder)
#include <Wire.h>     //I2c communication
#include <SPI.h>      //SPI communication
#include <PWMServo.h> //Commanding any extra actuators, installed with teensyduino installer
//#include <odometry_node.h>


#if defined USE_SBUS_RX
  #include "src/SBUS/SBUS.h"   //sBus interface
#endif

#if defined USE_DSM_RX
  #include "src/DSMRX/DSMRX.h"
#endif

#if defined USE_CRSF_RX
  #include <CRSFforArduino.hpp>
#endif

#if defined USE_MPU6050_I2C
  #include "src/MPU6050/MPU6050.h"
  MPU6050 mpu6050;
#else
  #error No IMU defined...
#endif

#if defined USE_MATEK3901 
  #include "src/MATEK3901/MATEK3901.h"
  Matek3901 matek;
#else 
  #error No Optical Flow Sensor defined...
#endif

//==========================================================================//
//                             USER-SPECIFIED VARIABLES                     //
//==========================================================================//
// Uncomment only one full scale gyro range (deg/sec)
#define GYRO_250DPS //Default
//#define GYRO_500DPS
//#define GYRO_1000DPS
//#define GYRO_2000DPS

// Uncomment only one full scale accelerometer range (G's)
#define ACCEL_2G //Default
//#define ACCEL_4G
//#define ACCEL_8G
//#define ACCEL_16G

// Setup gyro and accel full scale value selection and scale factor
#if defined USE_MPU6050_I2C
  #define GYRO_FS_SEL_250    MPU6050_GYRO_FS_250
  #define GYRO_FS_SEL_500    MPU6050_GYRO_FS_500
  #define GYRO_FS_SEL_1000   MPU6050_GYRO_FS_1000
  #define GYRO_FS_SEL_2000   MPU6050_GYRO_FS_2000
  #define ACCEL_FS_SEL_2     MPU6050_ACCEL_FS_2
  #define ACCEL_FS_SEL_4     MPU6050_ACCEL_FS_4
  #define ACCEL_FS_SEL_8     MPU6050_ACCEL_FS_8
  #define ACCEL_FS_SEL_16    MPU6050_ACCEL_FS_16
#endif

#if defined GYRO_250DPS
  #define GYRO_SCALE GYRO_FS_SEL_250
  #define GYRO_SCALE_FACTOR 131.0
#elif defined GYRO_500DPS
  #define GYRO_SCALE GYRO_FS_SEL_500
  #define GYRO_SCALE_FACTOR 65.5
#elif defined GYRO_1000DPS
  #define GYRO_SCALE GYRO_FS_SEL_1000
  #define GYRO_SCALE_FACTOR 32.8
#elif defined GYRO_2000DPS
  #define GYRO_SCALE GYRO_FS_SEL_2000
  #define GYRO_SCALE_FACTOR 16.4
#endif

#if defined ACCEL_2G
  #define ACCEL_SCALE ACCEL_FS_SEL_2
  #define ACCEL_SCALE_FACTOR 16384.0
#elif defined ACCEL_4G
  #define ACCEL_SCALE ACCEL_FS_SEL_4
  #define ACCEL_SCALE_FACTOR 8192.0
#elif defined ACCEL_8G
  #define ACCEL_SCALE ACCEL_FS_SEL_8
  #define ACCEL_SCALE_FACTOR 4096.0
#elif defined ACCEL_16G
  #define ACCEL_SCALE ACCEL_FS_SEL_16
  #define ACCEL_SCALE_FACTOR 2048.0
#endif

// Filter parameters - Defaults tuned for 2kHz loop rate;
float B_madgwick = 0.04;  // Madgwick filter parameter
float B_accel = 0.14;     // Accelerometer LP filter paramter (default: 0.14)
float B_gyro = 0.1;       // Gyro LP filter paramter (default: 0.1)

// Position Controller Low Pass Filter Values 
float A_positionX = 0.2; // LPF horizontal (X) filter
float A_positionY = 0.2; // LPF forward (Y) filter
float A_positionZ = 0.2; // LPF altitude (Z) filter

// Optical Flow Sensor Constants
const float FLOW_SCALE_X = -800.0f / 1000.0f;
const float FLOW_SCALE_Y = -800.0f / 1000.0f;
// Range of valid data from the VL53L0X, given by Matek themselves [8cm -> 200cm]
const float RANGEFINDER_INITIAL_HEIGHT_M = 0.0368f + 0.095f;
const float MAX_RANGE_M = 2.0f;
const float MIN_RANGE_M = 0.01f;

// IMU calibration parameters -
// calibrate IMU using calculate_IMU_error() in the void setup() to get these
// values, then comment out calculate_IMU_error()
float AccErrorX = 0.04;
float AccErrorY = 0.00;
float AccErrorZ = 0.05;
float GyroErrorX = -2.09;
float GyroErrorY = 0.29;
float GyroErrorZ = -1.17;

// OpFlow calibration parameters - Change on Startup
float rangeErrorZ = 0.043737385421991348 + 0.0128433;

// Controller parameters (take note of defaults before modifying!):
float i_limit = 25.0;              // Integrator saturation level, mostly for safety (default 25.0)
float maxRoll = 24.0;            // Max roll angle in degrees for angle mode (maximum ~70 degrees), deg/sec for rate mode
float maxPitch = 24.0;           // Max pitch angle in degrees for angle mode (maximum ~70 degrees), deg/sec for rate mode
float maxYaw = 128.0;            // Max yaw rate in deg/sec

float Kp_roll_angle = 0.12;      // Roll P-gain - angle mode
float Ki_roll_angle = 0.18;      // Roll I-gain - angle mode
float Kd_roll_angle = 0.03;      // Roll D-gain - angle mode (has no effect on controlANGLE2)
float B_loop_roll = 0.54;        // Roll damping term for controlANGLE2(), lower is more damping (must be between 0 to 1)
float Kp_pitch_angle = 0.12;     // Pitch P-gain - angle mode
float Ki_pitch_angle = 0.18;     // Pitch I-gain - angle mode
float Kd_pitch_angle = 0.03;     // Pitch D-gain - angle mode (has no effect on controlANGLE2)
float B_loop_pitch = 0.54;       // Pitch damping term for controlANGLE2(), lower is more damping (must be between 0 to 1)

float Kp_roll_rate = 0.0075;     // Roll P-gain - rate mode
float Ki_roll_rate = 0.0025;     // Roll I-gain - rate mode
float Kd_roll_rate = 0.00001;    // Roll D-gain - rate mode (be careful when increasing too high, motors will begin to overheat!)
float Kp_pitch_rate = 0.0075;    // Pitch P-gain - rate mode
float Ki_pitch_rate = 0.0025;    // Pitch I-gain - rate mode
float Kd_pitch_rate = 0.00001;   // Pitch D-gain - rate mode (be careful when increasing too high, motors will begin to overheat!)

float Kp_yaw = 0.18;             // Yaw P-gain
float Ki_yaw = 0.03;             // Yaw I-gain
float Kd_yaw = 0.00009;          // Yaw D-gain (be careful when increasing too high, motors will begin to overheat!)

// Optical Flow Controller Params
float Kp_positionX = 0.75;  // Horizontal (X-position) Proportional Gain
float Ki_positionX = 0.25;  // Horizontal (X-position) Integral Gain
float Kd_positionX = 0.50;  // Horizontal (X-position) Derivative Gain

float Kp_positionY = 1.00;  // Forward (Y-position) Proportional Gain
float Ki_positionY = 0.75;  // Forward (Y-position) Integral Gain
float Kd_positionY = 0.50;  // Forward (Y-position) Derivative Gain

float Kp_positionZ = 0.500;  // Altitude (Z-position) Proportional Gain
float Ki_positionZ = 0.008;  // Altitude (Z-position) Integral Gain
float Kd_positionZ = 0.250;  // Altitude (Z-position) Derivative Gain

float maxZ = 2.0;  // Maximum position on the Z-Axis in Meters

// Drone Characteristics
float hover_throttle = 0.485;
float drone_weight_kg = 0.97 + 0.005 + 0.104;

// Simulation Package
struct SensorPacket {
  float ax;
  float ay;
  float az;
  float gx;
  float gy;
  float gz;
  float range;
};

union SensorSerial {
  SensorPacket simulatedPkt;
  unsigned char serialStream[sizeof(SensorPacket)];
};

const unsigned char pktHeader[2] = {0xAA, 0x55};
const unsigned char pktFooter = 0xFE;
const bool simulatedEnvironment = true;
SensorSerial simulatedSensors;

// Radio failsafe values for every channel in the event that bad reciever
// data is detected. Recommended defaults:
// Defined: Throttle, Ail, Elevation, Rudder, Arm 1, Aux2
// TODO: Add parameters.yaml file to allow user to set
unsigned long thro_range[3] = {901 ,1106, 1311};  // Amount of Power
unsigned long ail_range[3]  = {901, 1106, 1311};  // Roll 
unsigned long ele_range[3]  = {901, 1106, 1311};  // Pitch 
unsigned long rud_range[3]  = {901, 1106, 1311};  // Yaw
unsigned long arm_range[2]  = {1000, 1792};        // Off/On
unsigned long channel_fs[6] = { thro_range[0], ail_range[1], ele_range[1], rud_range[1], 
                                arm_range[0], 1000 };

//==========================================================================//
//                                DECLARE PINS                              //
//==========================================================================//

// Note: If using SBUS, connect to pin 21 (RX5), if using DSM, connect to pin 15 (RX3)
// LED Pin : 13
// IMU Pins : SCL = 19, SDA = 18
// CRSF Pins: RX = 15, TX = 14
// Optical Flow Pins: RX = 16, TX = 17
//// Pinout Meanings:     throttle, ail, elevation, rudd, gear, aux1
// TODO: Add extra pins for certain flight modes using handset
const int channelPins[6] = {15,     16,  17,        20,    21,  22};
const int PPM_Pin = 23;

// OneShot125 ESC pin outputs (Had to go in reverse):
// Motor 1, 2, 3, 4
const int mPin[4] = {1, 2, 3, 4};

//==========================================================================//
//                            GLOBAL VARIABLES                              //
//==========================================================================//

// General stuff
float dt;
unsigned long current_time, prev_time;
unsigned long print_counter, serial_counter;
unsigned long blink_counter, blink_delay;
bool blinkAlternate;

// Radio communication:
unsigned long channel_pwm [6];
unsigned long channel_pwm_prev[4];

#if defined USE_CRSF_RX
  CRSFforArduino * crsf = nullptr;
  const int crsfChannels = 5;  // Move as needed based on Handheld
#endif
#if defined USE_SBUS_RX
  SBUS sbus(Serial3);
  uint16_t sbusChannels[16];
  bool sbusFailSafe;
  bool sbusLostFrame;
#endif
#if defined USE_DSM_RX
  DSM1024 DSM;
#endif

// IMU:
float AccX, AccY, AccZ;
float AccX_prev, AccY_prev, AccZ_prev;
float GyroX, GyroY, GyroZ;
float GyroX_prev, GyroY_prev, GyroZ_prev;
float roll_IMU, pitch_IMU, yaw_IMU;
float roll_IMU_prev, pitch_IMU_prev;
float q0 = 1.0f; //Initialize quaternion for madgwick filter
float q1 = 0.0f;
float q2 = 0.0f;
float q3 = 0.0f;

// Controller:
float error_roll, error_roll_prev, roll_des_prev, integral_roll, integral_roll_il, integral_roll_ol, integral_roll_prev, integral_roll_prev_il, integral_roll_prev_ol, derivative_roll, roll_PID = 0;
float error_pitch, error_pitch_prev, pitch_des_prev, integral_pitch, integral_pitch_il, integral_pitch_ol, integral_pitch_prev, integral_pitch_prev_il, integral_pitch_prev_ol, derivative_pitch, pitch_PID = 0;
float error_yaw, error_yaw_prev, integral_yaw, integral_yaw_prev, derivative_yaw, yaw_PID = 0;

// Normalized desired state:
float thro_des, roll_des, pitch_des, yaw_des;
float roll_passthru, pitch_passthru, yaw_passthru;

// Optical Flow Position Information:
float positionX_cur, positionY_cur, positionZ_cur = 0.0f;
float positionX_prev, positionY_prev, positionZ_prev = 0.0f;

// Optical Flow Twist Information:
float current_velocityX = 0.0f;
float current_velocityY = 0.0f;
float current_velocityZ = 0.0f;

float current_angular_velocityX = 0.0f;
float current_angular_velocityY = 0.0f;
float current_angular_velocityZ = 0.0f;

// Position Hold Controller:
bool valid_flow;

// X Values for all the various control methods
float error_positionX, error_positionX_prev = 0;
float positionX_des_prev, integral_positionX = 0;
float integral_positionX_il, integral_positionX_ol = 0;
float integral_positionX_prev, integral_positionX_prev_il, integral_positionX_prev_ol = 0;
float derivative_positionX, positionX_PID = 0;

// Y Values for all the various control methods
float error_positionY, error_positionY_prev = 0;
float positionY_des_prev, integral_positionY = 0;
float integral_positionY_il, integral_positionY_ol = 0;
float integral_positionY_prev, integral_positionY_prev_il, integral_positionY_prev_ol = 0;
float derivative_positionY, positionY_PID = 0;

// Z Values for all the various control methods
float error_positionZ, error_positionZ_prev = 0;
float positionZ_des_prev, integral_positionZ = 0;
float integral_positionZ_il, integral_positionZ_ol = 0;
float integral_positionZ_prev, integral_positionZ_prev_il, integral_positionZ_prev_ol = 0;
float derivative_positionZ, positionZ_PID = 0;

// Position Hold Desired States
float positionX_des, positionY_des, positionZ_des;
float positionX_passthru, positionY_passthru, positionZ_passthru;

// Mixer (Motors)
float m_command_scaled[4];
int m_command_PWM[4];

// Flight status
enum DroneState {
  DORMANT = 0,       // Not Armed, not Ready
  ARMED = 1,         // No Throttle, but Ready
  FLYING = 2,        // Armed and Given Throttle, Changing Position
  POSITION_HOLD = 3,  // No additional Throttle, Hold Position
  CRASHED = 4         // If we have hit something and cannot operate
};
DroneState droneState;

//==========================================================================//
//                                 VOID SETUP                               //
//==========================================================================//
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
   *  Simulates the void loop(), but only for the purpose of providing throttle pass through to the motors, so that you can
   *  power up with throttle at full, let ESCs begin arming sequence, and lower throttle to zero. This function should only be
   *  uncommented when performing an ESC calibration.
   */
   while (true) {
      prev_time = current_time;
      current_time = micros();
      dt = (current_time - prev_time)/1000000.0;

      digitalWrite(13, HIGH); //LED on to indicate we are not in main loop

      getCommands(); //Pulls current available radio commands
      failSafe(); //Prevent failures in event of bad receiver connection, defaults to failsafe values assigned in setup
      getDesState(); //Convert raw commands to normalized values based on saturated control limits
      getIMUdata(); //Pulls raw gyro, accelerometer, and magnetometer data from IMU and LP filters to remove noise
      Madgwick(GyroX, -GyroY, -GyroZ, -AccX, AccY, AccZ, dt); //Updates roll_IMU, pitch_IMU, and yaw_IMU (degrees)
      getDesState(); //Convert raw commands to normalized values based on saturated control limits
 
      for (int i = 0; i < 4; i++)
      {
        m_command_scaled[i] = thro_des;
      }

      scaleCommands(); //Scales motor commands to 125 to 250 range (OneShot125 protocol) and servo PWM commands to 0 to 180 (for servo library)
      //throttleCut(); //Directly sets motor commands to low based on state of ch5
      commandMotors(); //Sends command pulses to each motor pin using OneShot125 protocol

      printRadioData();
      printMotorCommands();
      printDesiredState();

      loopRate(2000); //Do not exceed 2000Hz, all filter parameters tuned to 2000Hz by default
   }
}

float floatFaderLinear(float param, float param_min, float param_max, float fadeTime, int state, int loopFreq){
  //DESCRIPTION: Linearly fades a float type variable between min and max bounds based on desired high or low state and time
  /*
   *  Takes in a float variable, desired minimum and maximum bounds, fade time, high or low desired state, and the loop frequency
   *  and linearly interpolates that param variable between the maximum and minimum bounds. This function can be called in controlMixer()
   *  and high/low states can be determined by monitoring the state of an auxillarly radio channel. For example, if channel_6_pwm is being
   *  monitored to switch between two dynamic configurations (hover and forward flight), this function can be called within the logical
   *  statements in order to fade controller gains, for example between the two dynamic configurations. The 'state' (1 or 0) can be used
   *  to designate the two final options for that control gain based on the dynamic configuration assignment to the auxillary radio channel.
   *
   */
  float diffParam = (param_max - param_min)/(fadeTime*loopFreq); //Difference to add or subtract from param for each loop iteration for desired fadeTime

  if (state == 1) { //Maximum param bound desired, increase param by diffParam for each loop iteration
    param += diffParam;
  } else if (state == 0) { //Minimum param bound desired, decrease param by diffParam for each loop iteration
    param -= diffParam;
  }

  param = constrain(param, param_min, param_max); //Constrain param within max bounds

  return param;
}

float floatFaderLinear2(float param, float param_des, float param_lower, float param_upper, float fadeTime_up, float fadeTime_down, int loopFreq){
  //DESCRIPTION: Linearly fades a float type variable from its current value to the desired value, up or down
  /*
   *  Takes in a float variable to be modified, desired new position, upper value, lower value, fade time, and the loop frequency
   *  and linearly fades that param variable up or down to the desired value. This function can be called in controlMixer()
   *  to fade up or down between flight modes monitored by an auxillary radio channel. For example, if channel_6_pwm is being
   *  monitored to switch between two dynamic configurations (hover and forward flight), this function can be called within the logical
   *  statements in order to fade controller gains, for example between the two dynamic configurations.
   *
   */
  if (param > param_des) { //Need to fade down to get to desired
    float diffParam = (param_upper - param_des)/(fadeTime_down*loopFreq);
    param -= diffParam;
  } else if (param < param_des) { //Need to fade up to get to desired
    float diffParam = (param_des - param_lower)/(fadeTime_up*loopFreq);
    param += diffParam;
  }

  param = constrain(param, param_lower, param_upper); //Constrain param within max bounds

  return param;
}

void throttleCut() {
  //DESCRIPTION: Directly set actuator outputs to minimum value if triggered
  /*
      Monitors the state of radio command channel_pwm[5] and directly sets the mx_command_PWM values to minimum (120 is
      minimum for OneShot125 protocol, 0 is minimum for standard PWM servo library used) if channel 5 is high. This is the last function
      called before commandMotors() is called so that the last thing checked is if the user is giving permission to command
      the motors to anything other than minimum value. Safety first.

      channel_pwm[5] is LOW then throttle cut is OFF and throttle value can change. (ThrottleCut is DEACTIVATED)
      channel_pwm[5] is HIGH then throttle cut is ON and throttle value = 120 only. (ThrottleCut is ACTIVATED), (drone is DISARMED)
  */
  if (droneState == DORMANT) {
    // Disarm the Motorrs
    for (int i = 0; i < 4; i++)
    {
      m_command_PWM[i] = 120;
    }

    // Should reset the current values as well since we'll be on the ground
    if (simulatedEnvironment) {
      simulationReset();
    }
  }
}

void odometryUpdate()
{
  float orientation[4] = {q0, q1, q2, q3};
  float position[3] = {1.0, 2.0, 3.0};
  float linear_velocity[3] = {0.0, 0.0, 0.0};
  float angular_velocity[3] = {0.0, 0.0, 0.0};
  //odom_pub_callback(orientation, position, linear_velocity, angular_velocity);
}

struct TelemetryPacket {
  float timestamp;
  float roll_PID, pitch_PID, yaw_PID;
  float posZ, desZ, z_PID;
  uint16_t pwm[4];
};

void writeTelemetryData()
{
  // DESCRIPTION: Send the motor PWM values to the Serial port for simulation
    TelemetryPacket pkt;
    pkt.timestamp = current_time/1000000.0f;
    pkt.posZ = positionZ_cur;
    pkt.desZ = positionZ_des;
    pkt.roll_PID = roll_PID;
    pkt.pitch_PID = pitch_PID;
    pkt.yaw_PID = yaw_PID;
    pkt.z_PID = positionZ_PID;
    pkt.pwm[0] = m_command_PWM[0];
    pkt.pwm[1] = m_command_PWM[1];
    pkt.pwm[2] = m_command_PWM[2];
    pkt.pwm[3] = m_command_PWM[3];
    
    Serial.write((uint8_t*)&pkt, sizeof(pkt));
}

void readSimulatedPeripherals()
{
  // DESCRIPTION: Read the "fake" peripheral values from sim to update drone
  // Use a State Based Enum to control index movement
  static enum { WAIT_HEADER_FIRST, WAIT_HEADER_SECOND, READ_PAYLOAD, WAIT_FOOTER } state = WAIT_HEADER_FIRST;
  static size_t index = 0;

  while (Serial.available()) {
    unsigned char currentByte = Serial.read();
    if (state == WAIT_HEADER_FIRST) {
        if (currentByte == pktHeader[0]) {
          state = WAIT_HEADER_SECOND;
        } 
    } else if (state == WAIT_HEADER_SECOND) {
        if (currentByte == pktHeader[1]) {
          index = 0;
          state = READ_PAYLOAD;
        } else {
          // back to start if not correct sequence
          state = WAIT_HEADER_FIRST;
        }
    } else if (state == READ_PAYLOAD) {
      simulatedSensors.serialStream[index++] = currentByte;
        if (index >= sizeof(SensorPacket)) {
          state = WAIT_FOOTER;
        }
    } else if (state == WAIT_FOOTER) {
      if (currentByte == pktFooter) {
          simulatedSensors.serialStream[index] = currentByte;
          index++;
        }
        // Regardless, reset to look for next header
        state = WAIT_HEADER_FIRST;
    }
  }
}
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

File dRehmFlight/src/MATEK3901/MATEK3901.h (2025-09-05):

#pragma once
#include <Arduino.h>
#include "MSPv2.h"

/**
 * Matek 3901-L0X adapter:
 *  - Watches incoming MSPv2 frames
 *  - Extracts flow_x (int32), flow_y (int32), range_mm (uint32) when the function ID matches
 *  - Provides simple low-pass filtering and a "freshness" flag
 */
class Matek3901 {
public:
  // Basic Constructor
  Matek3901();

  // Need to set up a the Serial port that the UART is connected to
  void begin(HardwareSerial & port, uint32_t baud);
  // Check to see if there's a change in action and "recall" the onframe function
  void poll();

  // ------------- Getter Functions -------------- //
  // Latest values (raw, unscaled)
  bool getFresh() const;
  int32_t getFlowX() const;
  int32_t getFlowY() const;
  uint32_t getRangeMM() const;
  uint32_t getLastUpdateMs() const;

  // Low Pass Filter Getters
  float getLPFFlowX() const;
  float getLPFFlowY() const;
  float getLPFRangeM() const;
  
  // ------------- Setter Functions -------------- //
  void setLPFAlpha(float a);

  // For debugging/bring-up
  void enableLogging(Stream * s);

private:
  HardwareSerial * serial = nullptr;
  MSPv2Parser parser{[&](const MSPv2Frame& f){  }};
  Stream * log = nullptr;
  
  // Neccessary IDs for the 2 chips
  const uint16_t RANGEFINDER_FUNC_ID = 0x1F01;
  const uint16_t OPFLOW_FUNC_ID = 0x1F02;

  // Raw values to extract
  int32_t  flow_x = 0;
  int32_t  flow_y = 0;
  uint32_t range_mm = 0;

  // Filter values to use
  float alpha = 0.5f;
  float lpf_flow_x = 0.0f;
  float lpf_flow_y = 0.0f;
  float lpf_range_mm = 0.0f;

  uint32_t last_ms = 0;
  bool fresh = false;

  void onFrame(const MSPv2Frame & f);

  // Parsing Functions to Break up the Stream
  void parseFlow(const  MSPv2Frame & f);
  void parseRange(const MSPv2Frame & f);

  // Filter the values for usable data
  void commitRange(uint32_t range_mm, uint8_t quality);
  void commitFlow(int32_t fx, int32_t fy, uint8_t quality);

  void printStream(const MSPv2Frame & f);
};  // End of Matek 3901 Class

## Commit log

2025-07-03 Uploadinng org original PCB with components
    [DEV-16771.step, ELRS_Lite_RX.kicad_pcb, ELRS_Lite_RX.kicad_sch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]
2025-07-08 Adding Gerbers
    [TeensyDrone-B_Cu.gbr, TeensyDrone-B_Mask.gbr, TeensyDrone-B_Silkscreen.gbr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]
2025-07-11 splitting files
    [MatekOpticalFlow.kicad_pcb, MatekOpticalFlow.kicad_sch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]
2025-07-17 Moved to Teensy 4.0 from 4.1
    [DEV-15583.step, DEV-16771.step, MatekOpticalFlow.kicad_pcb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]
2025-07-17 Revert "Moved to Teensy 4.0 from 4.1"
    This reverts commit 64f42becbd12878e856e1dc259d1d069ff850610.
    [DEV-15583.step, DEV-16771.step, MatekOpticalFlow.kicad_pcb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]
2025-07-17 Revert "splitting files"
    This reverts commit bca84f3fae8bf59e844e86045c33a7267805a79f.
    [MatekOpticalFlow.kicad_pcb, MatekOpticalFlow.kicad_sch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]
2025-07-17 Revert "Revert "splitting files""
    This reverts commit 3562b8e581463791a03922c4a90183042ac39a13.
    [MatekOpticalFlow.kicad_pcb, MatekOpticalFlow.kicad_sch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]
2025-07-17 Revert "Revert "Moved to Teensy 4.0 from 4.1""
    This reverts commit 7b94347de4182ec4fe07ca98d08f7a30d7e3d8b2.
    [DEV-15583.step, DEV-16771.step, MatekOpticalFlow.kicad_pcb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]
2025-07-18 Second iteration of PCB
    [TeensyDrone.kicad_pcb, TeensyDrone.kicad_sch]
2025-07-20 Teensy 4.0 Iteration 2
2025-07-25 Done Hardware Section
    [M2 Standoff(1).stl, M2-Standoff-ESC.stl, M2Standoff.3mf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]
2025-08-06 Working Code for Flipped Drone
    [dRehmFlight.ino, radioComm.ino]
2025-08-10 Adding drone URDF
    [back_wing.stl, base_link.stl, f_drone.urdf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]
2025-08-17 Function URDF/SDF Models for RViz/Gazebo
    [back_wing.stl, base_link.stl, basic_link.stl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]
2025-08-20 Adding Technical Review Documents
    [drone_world.sdf, model.sdf, model.urdf]
2025-09-05 Acquired Hardware In the Loop (HIL)
    [2s_battery.stl, backup_model.sdf, box_world.sdf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]
2026-09-21 Functioning Teleop Drone Demo & Changing to ros_gz_project_template
    [2_pinheaders.stl, 2s_battery.stl, 4_motormounts.stl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]
2026-09-24 Improving Hardware-In-The-Loop (HIL) Capabilities
    [Custom_PCB.stl, ESC.stl, IMU.stl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]
